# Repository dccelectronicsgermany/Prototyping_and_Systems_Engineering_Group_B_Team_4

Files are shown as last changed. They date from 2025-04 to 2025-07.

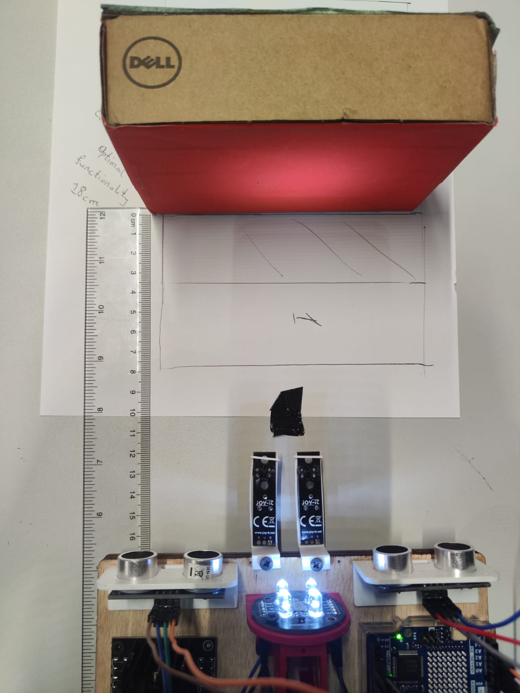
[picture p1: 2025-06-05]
Testing/ColorSensor_Testing/Calibration_of_ColorSensor_ 2025-06-05.jpeg

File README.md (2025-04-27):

## Autonomous Lane-Following and Obstacle-Avoiding Vehicle

 # Project Overview
This project involves the design and implementation of an autonomous vehicle capable of:
- Following a lane based on a color using infrared sensors.
- Detecting obstacles on its path using ultrasonic sensors.
- Changing its route dynamically to avoid obstacles while following the lane.
(without human intervention)

The vehicle uses an Arduino Uno microcontroller and standard robotic hardware components.
 #  Hardware Components
- Chassis (Robot car frame)
- 2 Motor controllers (for driving the wheels)
- 2 Tires
- Breadboard (for circuit prototyping)
- Arduino Uno (central control unit)
- 2 Ultrasonic sensors (for obstacle detection)
- 2 Infrared sensors (for lane detection based on color contrast)
- LiPo Battery (for powering the system)
- ON/OFF Switch (for power management)
 # Functionality Description
- Lane Following:
The vehicle uses two infrared sensors placed underneath to detect lane markings. It adjusts the motor speed and direction to stay within the lane based on color contrast (typically dark lines on a lighter surface).

- Obstacle Detection and Avoidance:
Two ultrasonic sensors monitor the surroundings. When an obstacle is detected within a predefined distance:
The vehicle slows down.
Makes a directional decision (left or right) based on available space.
Reorients itself and continues following the lane.

- Power Management:
The vehicle is powered by a rechargeable LiPo battery, and the system can be turned ON or OFF using a physical switch.

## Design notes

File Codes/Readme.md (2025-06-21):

# Arduino UNO R4 WiFI Modular Robot System

This project is a modular, extensible robot control system based on:

- Line following (PID)
- Obstacle avoidance (Ultrasonic + Color)
- Modular C++ architecture (IR, Motors, PID, Movement...)

## Structure
- `Motor.h/.cpp`: Motor abstraction
- `IRSensor`, `UltrasonicSensor`, `ColorSensor`: Sensor modules
- `MovementController`: Handles motion logic
- `ObstacleHandler`: Obstacle evasion behavior
- `ObstacleChecker`: Central sensor processor
- `PIDController`: For smooth line following

## Board
- Arduino Nano R4 WiFi

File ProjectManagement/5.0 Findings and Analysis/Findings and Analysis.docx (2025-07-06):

Findings and Analysis:

The following section presents the key findings obtained during the project, along with a detailed analysis. These results are based on the data collected, observations made, and methods applied throughout the project.

Sensor Behavior and Accuracy

- Ultrasonic Sensors: Successfully detected obstacles within a range of 18cm with an average error margin of ±1cm.
- Infrared Sensors: Accurately detected line paths, but performance was affected by lighting and surface texture.
- Colour Sensor: Could reliably distinguish between Red and Green surfaces under good lighting conditions.

PID Controller Tuning

- Initial PID values: Kp = 100, Ki = 100, Kd = 100
- Observed that:
  - High Kp caused the robot to oscillate.
  - Ki helped reduce long term drift but too much made it unstable.
  - Kd improved sharp turns and reduced overshoot.
- Final tuned values: Kp = 10, Ki = 5, Kd = 10 – provided smooth line following with minimal overshooting.

State Machine Performance

- The state transitions worked correctly between:
  - Line following
  - Obstacle avoidance
  - Turning logic
- Edge cases (e.g., obstacles, tight corners) were handled with a delay of 200ms on average.

System Limitations

- Sensor noise occasionally caused false obstacle detection.
- Bright ambient light interfered with IR accuracy.
- Tuning PID required trial and error and was environment dependent.

Performance Metrics

- Average lap time on test track: 29 seconds
- Success rate for completing track without collision: 90%

A pre-requisite report for completion of Prototyping and Systems Engineering Course: To: Professor Stephen Henkler By Group B 4 students : Chimezie, Daniel Chidi [ Mat.Nr. 1230515 ] daniel-chidi.chimezie@stud.hshl.de Cho Bertrand Mungu [ Mat.Nr. 2220052 ] bertrand-mungu.cho@stud.hshl.de Ghimire, R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

2 SYSTEMS ENGINEERING AND PROTOTYPING COURSE Prototyping Technical Report: The Design and Construction of Autonomous Vehicle

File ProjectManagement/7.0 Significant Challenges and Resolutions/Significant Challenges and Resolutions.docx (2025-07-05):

Significant Challenges and Resolutions:

Throughout the development and testing of the autonomous vehicle, several technical and practical challenges were encountered. These challenges provided valuable learning opportunities and required iterative problem-solving, adjustments to the hardware and software, and fine-tuning of system performance. Below is a summary of the key challenges faced during the project and the solutions implemented to overcome them.

Sensor Inaccuracy and Interference

- Challenge: The IR and ultrasonic sensors sometimes gave inconsistent or false readings, especially in bright lighting or when objects were at awkward angles.
- Resolution: Implemented multiple readings and averaging (for color sensor), timing intervals for ultrasonic checks and added logic to ignore clearly invalid values.

Obstacle Avoidance Complexity

- Challenge: Designing an effective obstacle avoidance routine that didn’t cause the robot to get lost or stuck after detouring.
- Resolution: Created a step-by-step avoidance sequence including reverse, pivot, bypass, and line recovery with fail-safe search patterns -ensured the robot could return to the line reliably.

Line Loss and Path Recovery

- Challenge: When both IR sensors lost the line (e.g., at junctions or sharp curves), the robot didn’t always know which way to turn.
- Resolution: Tracked the last seen position of the line using lastSeenLine logic and implemented directional searches (pivot left/right) to regain the path.

Color Detection Reliability

- Challenge: Colours were sometimes misclassified due to ambient lighting or variations in surface tone.
- Resolution: Collected calibrated colour ratios (RG and RB) and added a differential comparison strategy instead of relying on raw RGB values - improved classification accuracy between Colour A and B.

Tuning PID Controller

- Challenge: The robot either over-corrected or didn't respond well to line deviations during movement.
- Resolution: Tuned the PID constants (Kp, Ki, Kd) through trial and error to achieve smoother turns and better line-following stability.

Code Integration and Timing Conflicts

- Challenge: Running multiple sensor routines (IR, ultrasonic, colour) caused timing conflicts and delayed responses.
- Resolution: Used timing intervals (millis) instead of delay() for obstacle checks and optimized sensor polling frequency to balance responsiveness and stability.

A pre-requisite report for completion of Prototyping and Systems Engineering Course: To: Professor Stephen Henkler By Group B 4 students : Chimezie, Daniel Chidi [ Mat.Nr. 1230515 ] daniel-chidi.chimezie@stud.hshl.de Cho Bertrand Mungu [ Mat.Nr. 2220052 ] bertrand-mungu.cho@stud.hshl.de Ghimire, R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

2 SYSTEMS ENGINEERING AND PROTOTYPING COURSE Prototyping Technical Report: The Design and Construction of Autonomous Vehicle

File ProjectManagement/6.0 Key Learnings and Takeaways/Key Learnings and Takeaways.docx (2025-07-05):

Key Learnings and Takeaways:

Working on the autonomous vehicle gave us valuable insight into how complex it can be to design a functional system in real life. Some of the major takeaways we had include;

Understanding Autonomous Systems

- Gained practical insight into how autonomous vehicles perceive their environment using sensors like ultrasonic, Infrared and color sensors.
- Learned how decision making is handled through state machines and sensor inputs.

Sensor Integration Challenges

- Realized that real world sensor data is noisy and can be affected by environmental conditions (e.g., lighting, surface reflectivity).

PID Control in Real Life

- Learned how a PID controller is used to achieve smooth line following.
- Understood the role of tuning kp, ki and kd for optimal movement balancing responsiveness and stability.

System Thinking

- Understood the importance of combining hardware, software and control logic into a cohesive system.
- Experienced how small issues in one component (e.g., a sensor) can impact overall system behavior.

Programming and Logic Development

- Improved skills in C/C++ programming using Arduino IDE.
- Learned to design modular code with functions, state machines and helper routines.
- Developed debugging skills by using serial output for troubleshooting sensor behavior.

Project Planning and Iteration

- Learned the value of testing in stages – first the motors, then sensors and then integration.
- Iteratively refined the system through testing, debugging and improvements.

A pre-requisite report for completion of Prototyping and Systems Engineering Course: To: Professor Stephen Henkler By Group B 4 students : Chimezie, Daniel Chidi [ Mat.Nr. 1230515 ] daniel-chidi.chimezie@stud.hshl.de Cho Bertrand Mungu [ Mat.Nr. 2220052 ] bertrand-mungu.cho@stud.hshl.de Ghimire, R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

2 SYSTEMS ENGINEERING AND PROTOTYPING COURSE Prototyping Technical Report: The Design and Construction of Autonomous Vehicle

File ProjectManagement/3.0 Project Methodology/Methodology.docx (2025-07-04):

3. Project Methodology:

. Methodology

The development of the autonomous robotic vehicle was carried out in structured phases, covering mechanical design, sensor calibration, embedded software development, and iterative testing.

Hardware Design

A two-wheeled differential drive robotic chassis was constructed, integrating essential components for autonomous navigation and decision-making. The key hardware includes:

- Arduino Uno R4 microcontroller – acts as the central control unit for all peripherals.
- IR lane-following sensors – detect the contrast between the lane and the background.
- Ultrasonic sensors (HC-SR04) – provide obstacle distance measurements for real-time avoidance.
- TCS3200 color sensor – a color-to-frequency converter used to detect the color of objects based on RGB reflectance.
- SBC Motor Driver 2 – controls the motors with suitable current and voltage for bidirectional motion.
- 12V LiPo battery with switch – powers the entire system, providing consistent voltage and current for reliable operation.

The mechanical frame, including chassis structure, sensor holders, and battery mounts, was designed using SolidWorks. This CAD-based approach ensured accurate placement, structural integrity, and modular design for component accessibility and replacement.

Sensor Calibration and Integration

All sensors were calibrated and tested before integration to ensure accurate data acquisition and system stability:

- IR Sensors: Tuned to detect lane boundaries using reflectance-based thresholding, optimized for the test surface.
- Ultrasonic Sensors: Configured with distance thresholds to trigger avoidance behavior when obstacles are within proximity.
- TCS3200 Color Sensor: Calibrated using reference color samples. The sensor uses photodiodes with RGB filters and outputs a frequency proportional to the intensity of each component. Color classification was achieved by comparing frequency ratios of red, green, and blue channels.

Software Development

Firmware was written using the Arduino IDE in C++, with a modular structure for sensor reading, motor control, and decision logic:

- Lane Following: Implemented with basic PID logic to maintain position within the lane using IR sensor input.
- Obstacle Avoidance: Ultrasonic data triggered directional changes when obstacles were detected within a predefined range.
- Color-Based Behavior: TCS3200 output was analyzed to determine object color and adjust behavior accordingly—e.g., stopping or rerouting.

Testing and Iteration

The system was tested under different physical and environmental conditions to ensure functionality and robustness:

- Sensor Accuracy: Each sensor’s performance was verified under varying lighting and surface reflectivity conditions.
- Navigation Robustness: Evaluated system behavior during lane exits, sharp turns, and reentry, ensuring consistent responsiveness.
- Environmental Adaptability: Testing included both indoor and semi-outdoor environments to assess sensor stability and overall system reliability.

Each iteration guided hardware and software refinements, with component placements and mountings reworked in SolidWorks for better alignment and stability, resulting in a reliable and efficient robotic system.

A pre-requisite report for completion of Prototyping and Systems Engineering Course: To: Professor Stephen Henkler By Group B 4 students : Chimezie, Daniel Chidi [ Mat.Nr. 1230515 ] daniel-chidi.chimezie@stud.hshl.de Cho Bertrand Mungu [ Mat.Nr. 2220052 ] bertrand-mungu.cho@stud.hshl.de Ghimire, R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

4 SYSTEMS ENGINEERING AND PROTOTYPING COURSE Prototyping Technical Report: The Design and Construction of Autonomous Vehicle

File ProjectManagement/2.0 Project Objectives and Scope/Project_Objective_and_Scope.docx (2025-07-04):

2. Project Objectives and Scope:

The primary objective of this project is to design and

develop an autonomous robotic vehicle capable of navigating

dynamic environments using a sensor-driven control system.

The following key goals guide the design and implementation

phases:

• Autonomous Lane Following: Develop a reliable lane-

following mechanism using Infrared (IR) sensors. The

system should be capable of detecting and tracking pre-

defined lanes with precision, including handling curves

and intersections effectively.

• Obstacle Detection and Avoidance: Integrate ultrasonic

sensors to facilitate real-time obstacle detection. The

robotic vehicle should be able to measure distance to

nearby objects and initiate avoidance maneuvers au-

tonomously to prevent collisions.

• Color-Based Decision Making: Implement a color

recognition system to classify and respond to different

types of obstacles. For example, red objects may signal a

full stop, while green may indicate a clear path or require

an alternate route. This enables dynamic and context-

aware navigation.

• Modular and Power-Efficient Design: Design the hard-

ware to be modular, allowing easy replacement and

testing of individual components. Power efficiency will

be emphasized to prolong operational time, utilizing op-

timized power management strategies across all modules.

Scope of the Project

This project encompasses both hardware and embedded

software development, with a strong emphasis on reliability,

sensor fusion, and system integration. Key aspects of the scope

include:

• Hardware Integration and Mechanical Design: Selec-

tion, configuration, and interfacing of sensors (IR and

ultrasonic), motor drivers, microcontrollers, and power

supply units. Custom mechanical components—such

as sensor holders, battery enclosures, and structural

frames—were designed using SolidWorks. This CAD-

based approach allowed for accurate measurements, mod-

ularity, and efficient assembly of all physical parts.

• Software Development: Development of embedded

firmware to process sensor data, control actuators, and

execute decision-making algorithms. Emphasis will be

placed on efficient code structure, interrupt-driven design,

and real-time responsiveness.

• System Testing and Validation: Rigorous testing will

be conducted to evaluate the system’s performance under

different environmental conditions. This includes assess-

ing the accuracy of lane-following, obstacle detection

range, decision logic correctness, and overall system

robustness.

• Scalability and Extensibility: While the initial prototype

will demonstrate core functionalities, the system will be

designed with future enhancements in mind, including

potential wireless communication, machine learning in-

tegration, or advanced navigation algorithms.

In summary, this project aims to deliver a functional,

intelligent robotic vehicle by effectively integrating sensing,

decision-making, mechanical design, and control into a uni-

fied, modular, and energy-efficient system.

A pre-requisite report for completion of Prototyping and Systems Engineering Course: To: Professor Stephen Henkler By Group B 4 students : Chimezie, Daniel Chidi [ Mat.Nr. 1230515 ] daniel-chidi.chimezie@stud.hshl.de Cho Bertrand Mungu [ Mat.Nr. 2220052 ] bertrand-mungu.cho@stud.hshl.de Ghimire, R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

5 SYSTEMS ENGINEERING AND PROTOTYPING COURSE Prototyping Technical Report: The Design and Construction of Autonomous Vehicle

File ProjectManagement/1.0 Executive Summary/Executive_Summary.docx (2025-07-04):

1. Executive Summary:

The rapid advancement of automation and embedded systems has paved the way for intelligent robotic platforms that can perform tasks with minimal human intervention. This project focuses on designing and implementing an autonomous robotic vehicle that can follow a defined path and avoid obstacles using a combination of infrared (IR), ultrasonic, and color sensors. The goal is to develop a functional prototype that simulates intelligent pathfinding and decision-making mechanisms suitable for real-world environments such as automated delivery systems or industrial navigation.

The robotic system is equipped with IR sensors to detect black lines on a contrasting surface, enabling it to follow a designated route. Ultrasonic sensors serve as proximity detectors, allowing the robot to recognize and react to obstacles within its path. A color sensor is also integrated to enhance decision-making by identifying the color characteristics of encountered objects. Based on predefined color criteria, the robot can classify objects such as `Color A` and `Color B`, influencing its navigation behavior accordingly.

A key highlight of the system is its modularity and low cost. The robot is built on a simple two-wheel chassis and powered by an Arduino Uno R4 microcontroller. Peripheral components, including an L298N motor driver, a 7.4V LiPo battery, and a power switch, provide essential control and energy management. This architecture supports expandability and makes the robot suitable for educational and research-oriented applications.

The software architecture is implemented using the Arduino IDE in embedded C++, with a focus on real-time performance. The line-following algorithm relies on digital feedback from the IR sensors, while obstacle avoidance is triggered by distance thresholds defined for the ultrasonic sensor. When an obstacle is detected, the robot either pauses or takes a detour, depending on the color of the object. For example, if the color sensor identifies a specific hue within a known RGB ratio range (Color A or B), the robot modifies its path accordingly—either rerouting, stopping, or re-centering on the line after bypassing the obstacle.

The development process was iterative, involving extensive hardware calibration and software testing under different lighting and surface conditions. The IR sensors were tuned for high contrast detection, and ultrasonic sensor readings were smoothed to minimize false positives. Color detection was verified using known samples to ensure consistent classification accuracy.

As of this report, the robot reliably demonstrates autonomous line-following behavior, detects and avoids obstacles within a 25 cm range, and reacts differently based on object color. This project serves as a practical proof-of-concept for sensor integration and autonomous decision-making in embedded systems, laying the foundation for more advanced robotics projects in the future.

A pre-requisite report for completion of Prototyping and Systems Engineering Course: To: Professor Stephen Henkler By Group B 4 students : Chimezie, Daniel Chidi [ Mat.Nr. 1230515 ] daniel-chidi.chimezie@stud.hshl.de Cho Bertrand Mungu [ Mat.Nr. 2220052 ] bertrand-mungu.cho@stud.hshl.de Ghimire, R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

2 SYSTEMS ENGINEERING AND PROTOTYPING COURSE Prototyping Technical Report: The Design and Construction of Autonomous Vehicle

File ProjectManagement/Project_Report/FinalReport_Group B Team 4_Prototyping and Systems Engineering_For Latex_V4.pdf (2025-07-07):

## UNIVERSITY OF APPLIED SCIENCES, HAMM-LIPPSTADT, GERMANY

### SYSTEMS ENGINEERING AND PROTOTYPING

### DESIGN AND IMPLEMENTATION OF A LINE FOLLOWING AND OBSTACLE AVOIDANCE ROBOT

### A COURSE WORK PROJECT FOR SUMMER SEMESTER 2025:

### A PREREQUISITE FOR COMPLETION OF PROTOTYPING AND SYSTEMS ENGINEERING COURSE AT THE UNIVERSITY OF APPLIED SCIENCES, HAMM-LIPPSTADT

## PRESENTED TO:

## PROFESSOR STEFAN HENKLER DR. FAEZEH PASANDIDEH MR. GIDO WAHRMANN

BY:

## GROUP B TEAM 4

## CHIMEZIE, DANIEL CHIDI / MAT.NR. 1230515 / DANIEL-CHIDI.CHIMEZIE@STUD.HSHL.DE

## CHO, BERTRAND MUNGU / MAT.NR. 2220052 / BERTRAND-MUNGU.CHO@STUD.HSHL.DE

## GHIMIRE, RIWAJ / MAT.NR. 1232171 / RIWAJ.GHIMIRE@STUD.HSHL.DE

## JULY 8, 2025

2 | P a g e

## 1.0 EXECUTIVE SUMMARY

The rapid advancement of automation and embedded systems have paved the way for the development of intelligent robotic systems that can perform tasks with minimal human intervention. This project focuses on designing and implementing an autonomous robotic vehicle that can follow a defined path and avoid obstacles using a combination of infrared (IR), ultrasonic and color sensors. The goal is to develop a functional prototype that simulates intelligent pathfinding and decision-making mechanisms suitable for real-world environments such as automated delivery systems or industrial navigation.

The robotic system is equipped with IR sensors to detect black lines on a contrasting surface, enabling it to follow a designated route. Ultrasonic sensors serve as proximity detectors, allowing the robot to recognize and react to obstacles within its path. A color sensor is also integrated to enhance decision-making by identifying the color characteristics of encountered objects. Based on predefined color criteria, the robot can classify objects such as `Color A` and `Color B`, influencing its navigation behavior accordingly [2].

A key highlight of the system is its modularity and low cost. The robot is built on a simple three-wheel chassis and powered by an Arduino Uno R4 Wi-Fi microcontroller. Peripheral components, including an L298N motor driver, a 12 V LiPo battery, and a power switch, provide essential control and energy management. This architecture supports expandability and makes the robot suitable for educational and research-oriented applications[4].

The software architecture is implemented using the Arduino IDE [1] in embedded C++, with a focus on real-time performance. The line-following algorithm relies on digital feedback from the IR sensors, while obstacle avoidance is triggered by distance thresholds defined for the ultrasonic sensor [2]. When an obstacle is detected, the robot either pauses or takes a detour, depending on the color of the object. For example, if the color sensor identifies a specific hue within a known RGB ratio range (Color A or B), the robot modifies its path accordingly, by either rerouting, stopping or re-centering on the line after bypassing the obstacle.

The development process was iterative, involving extensive hardware calibration and software testing under different lighting and surface conditions. The IR sensors were tuned for high contrast detection, and ultrasonic sensor readings were smoothed to minimize false positives. Color detection was verified using known samples to ensure consistent classification accuracy [2].

The robot we developed reliably demonstrates autonomous line-following behavior, detects and avoids obstacles within a 25 cm range, and reacts differently based on object color. This project serves as a practical proof-of-concept for sensor integration and autonomous decision-making in embedded systems, laying the foundation for more advanced robotics projects in the future.

3 | P a g e

## 2.0 PROJECT OBJECTIVES AND SCOPE

### 2.1 Objective:

The primary objective of this project is to design and develop an autonomous robotic vehicle capable of navigating dynamic environments using a sensor driven control system.

The following key goals guide the design and implementation phases:

a) Autonomous Lane Following: Develop a reliable lane-following mechanism using Infrared (IR) sensors. The system should be capable of detecting and tracking pre-defined lanes with precision, including handling curves and intersections effectively.
b) Obstacle Detection and Avoidance: Integrate ultrasonic sensors to facilitate real-time obstacle detection. The robotic vehicle should be able to measure distance to
nearby objects and initiate avoidance manoeuvres autonomously to prevent collisions[2].
c) Colour-Based Decision Making: Implement a colour recognition system to classify and respond to different types of obstacles. For example, red objects may signal a full stop, while green may indicate a clear path or require an alternate route. This enables dynamic and context-aware navigation.
d) Modular and Power-Efficient Design: Design the hardware to be modular, allowing easy replacement and testing of individual components. Power efficiency will be emphasized to prolong operational time, utilizing optimized power management strategies across all modules.

### 2.2 Project scope:

This project encompasses both hardware and embedded software development, with a strong emphasis on reliability, sensor fusion, and system integration. Key aspects of the scope include:

a) Hardware Integration and Mechanical Design: Selection, configuration and interfacing of sensors (IR, Colour and ultrasonic), motor drivers, microcontrollers, and power supply units. Custom mechanical components such as sensor holders, battery enclosures, and structural frames were designed using SolidWorks. This CAD-based approach allowed for accurate measurements, modularity, and efficient assembly of all physical parts[4].
b) Software Development: Development of embedded firmware to process sensor data, control actuators, and execute decision-making algorithms. Emphasis will be placed on efficient code structure, interrupt-driven design and real-time responsiveness.
c) System Testing and Validation: Rigorous testing will be conducted to evaluate the system’s performance under different environmental conditions. This includes assessing the accuracy of lane-following, obstacle detection range, decision logic correctness, and overall system robustness.
d) Scalability and Extensibility: While the initial prototype will demonstrate core functionalities, the system will be designed with future enhancements in mind, including potential wireless communication, machine learning integration, or advanced navigation algorithms.
In summary, this project aims to deliver a functional, intelligent robotic vehicle by effectively integrating sensing, decision-making, mechanical design, and control into a unified, modular, and energy-efficient system.

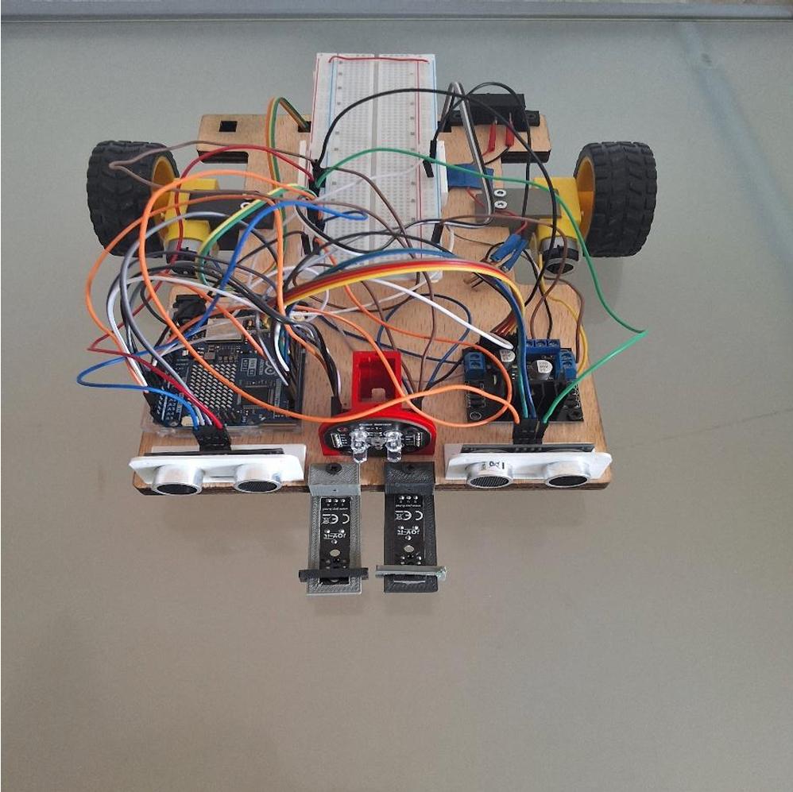
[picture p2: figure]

4 | P a g e

## 3.0 PROJECT METHODOLOGY

The primary objective of this project is to design and develop an autonomous robotic vehicle capable of navigating dynamic environments using a sensor-driven control system.

The following key goals guide the design and implementation phases:

a) Autonomous Lane Following: To develop a reliable lane-following mechanism using Infrared (IR) sensors. The system should be capable of detecting and tracking pre-defined lanes with precision, including handling curves and intersections effectively.
b) Obstacle Detection and Avoidance: To integrate ultrasonic sensors to facilitate real-time obstacle detection. The robotic vehicle should be able to measure distance to nearby objects and initiate avoidance manoeuvres autonomously to prevent collisions [2].
c) Colour-Based Decision Making: To implement a colour recognition system to classify and respond to different types of obstacles. For example, red objects may signal a full stop, while green may indicate a clear path or require an alternate route. This enables dynamic and context-aware navigation.
d) Modular and Power-Efficient Design: Design the hardware to be modular, allowing easy replacement and testing of individual components. Power efficiency will be emphasized to prolong operational time, utilizing optimized power management strategies across all modules.

## 3.1 Mechanical Designs:

## CAD Designs of spare parts using SolidWorks Software

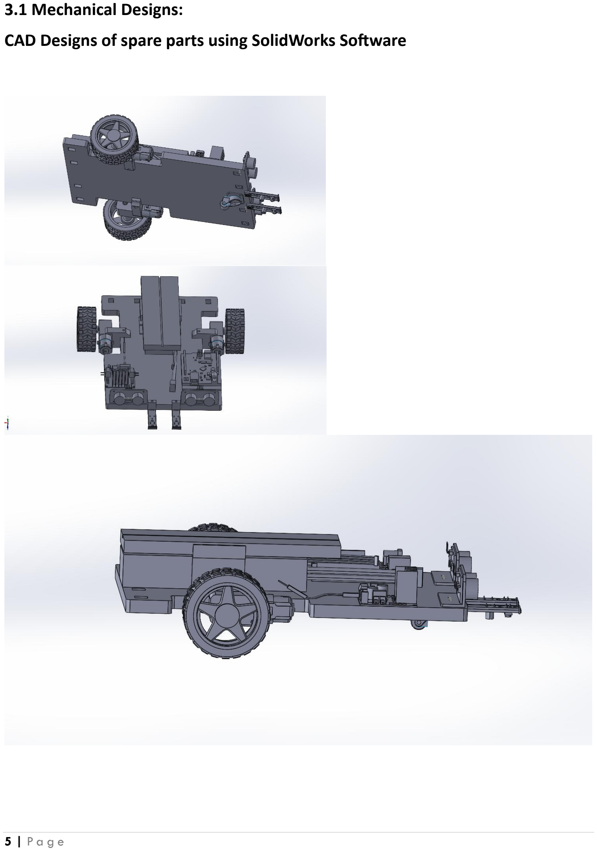
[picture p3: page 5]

5 | P a g e

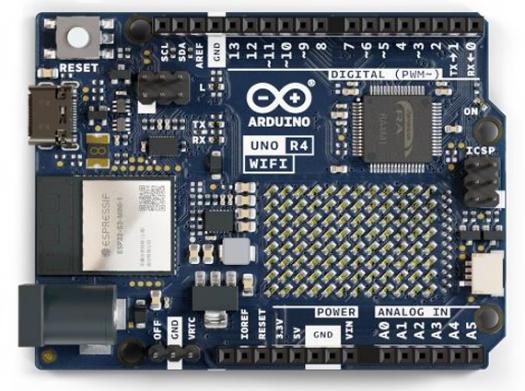
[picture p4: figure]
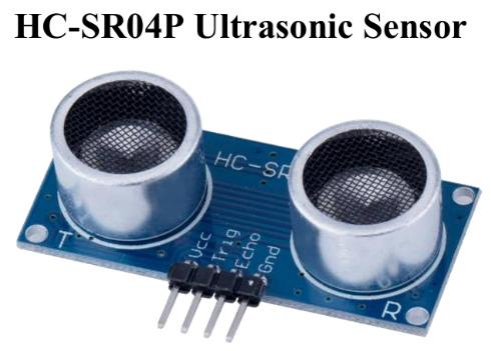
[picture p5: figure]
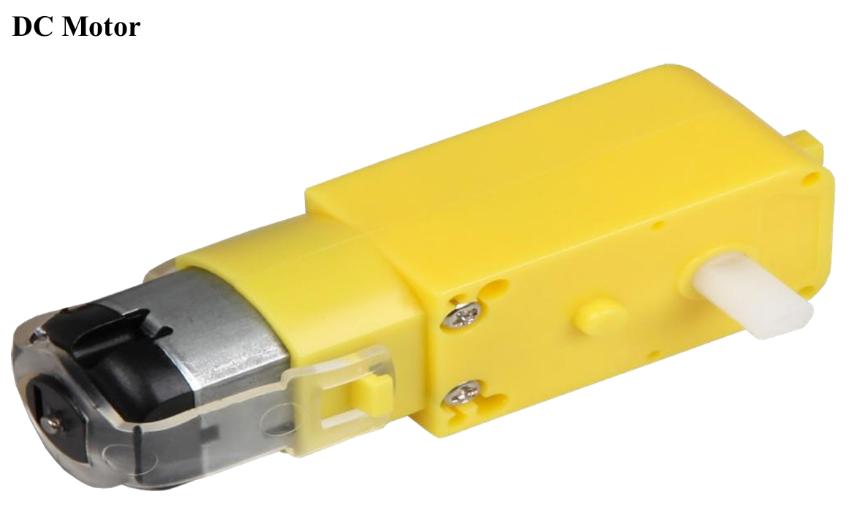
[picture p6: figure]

6 | P a g e

## 3.2 Electrical Components

Arduino Uno R4 WiFi | SBC-Motor Driver 2 | IR Sensor

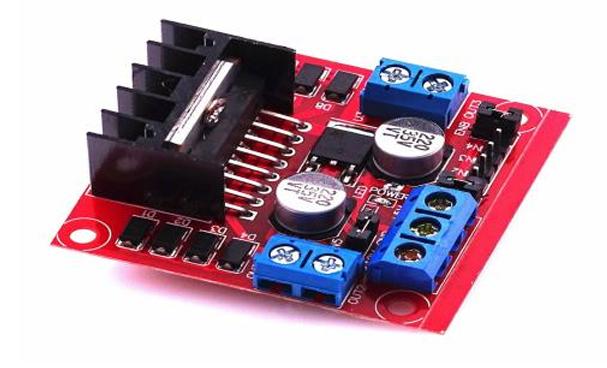
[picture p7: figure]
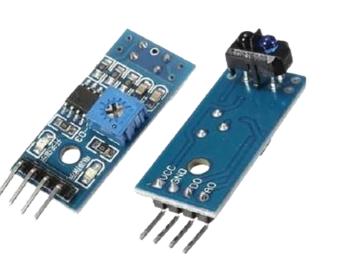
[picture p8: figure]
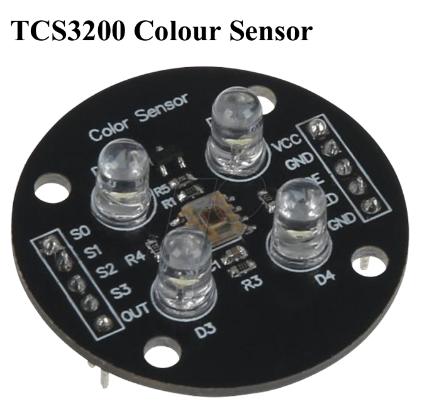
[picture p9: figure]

## 3.2.1 Electrical Schematics and Arrangements:

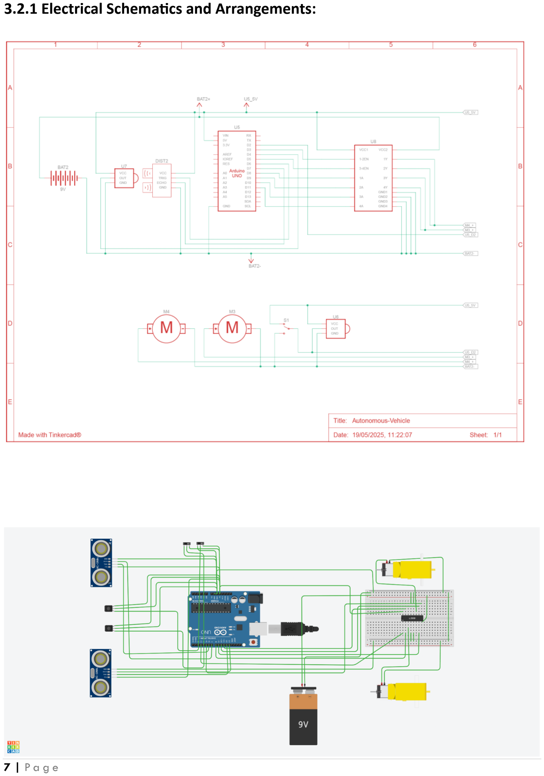
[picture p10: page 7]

7 | P a g e

## 3.3 System Engineering Architecture

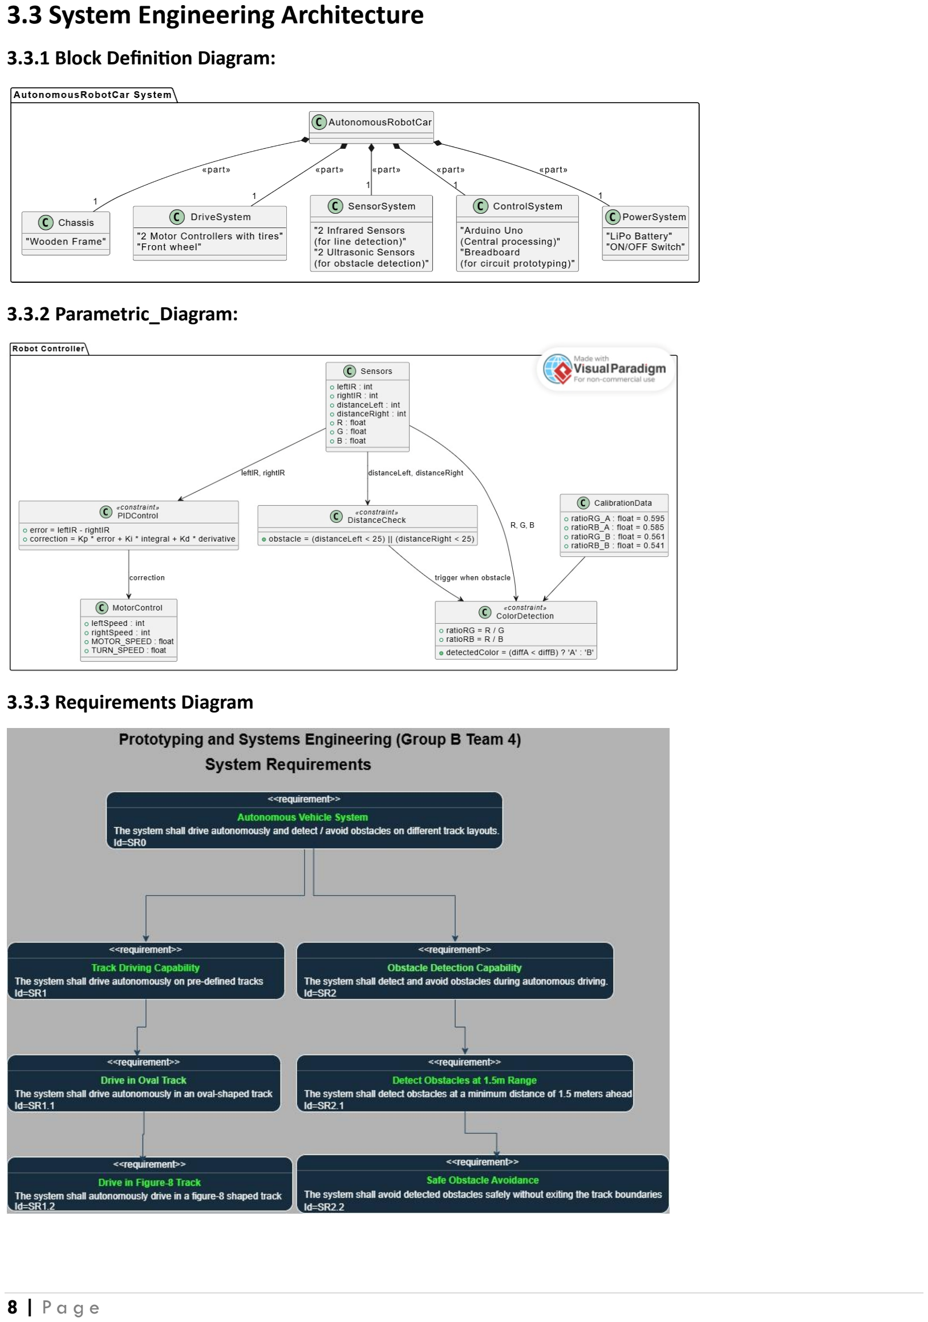
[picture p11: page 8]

8 | P a g e

### 3.3.1 Block Definition Diagram:

### 3.3.2 Parametric_Diagram:

### 3.3.3 Requirements Diagram

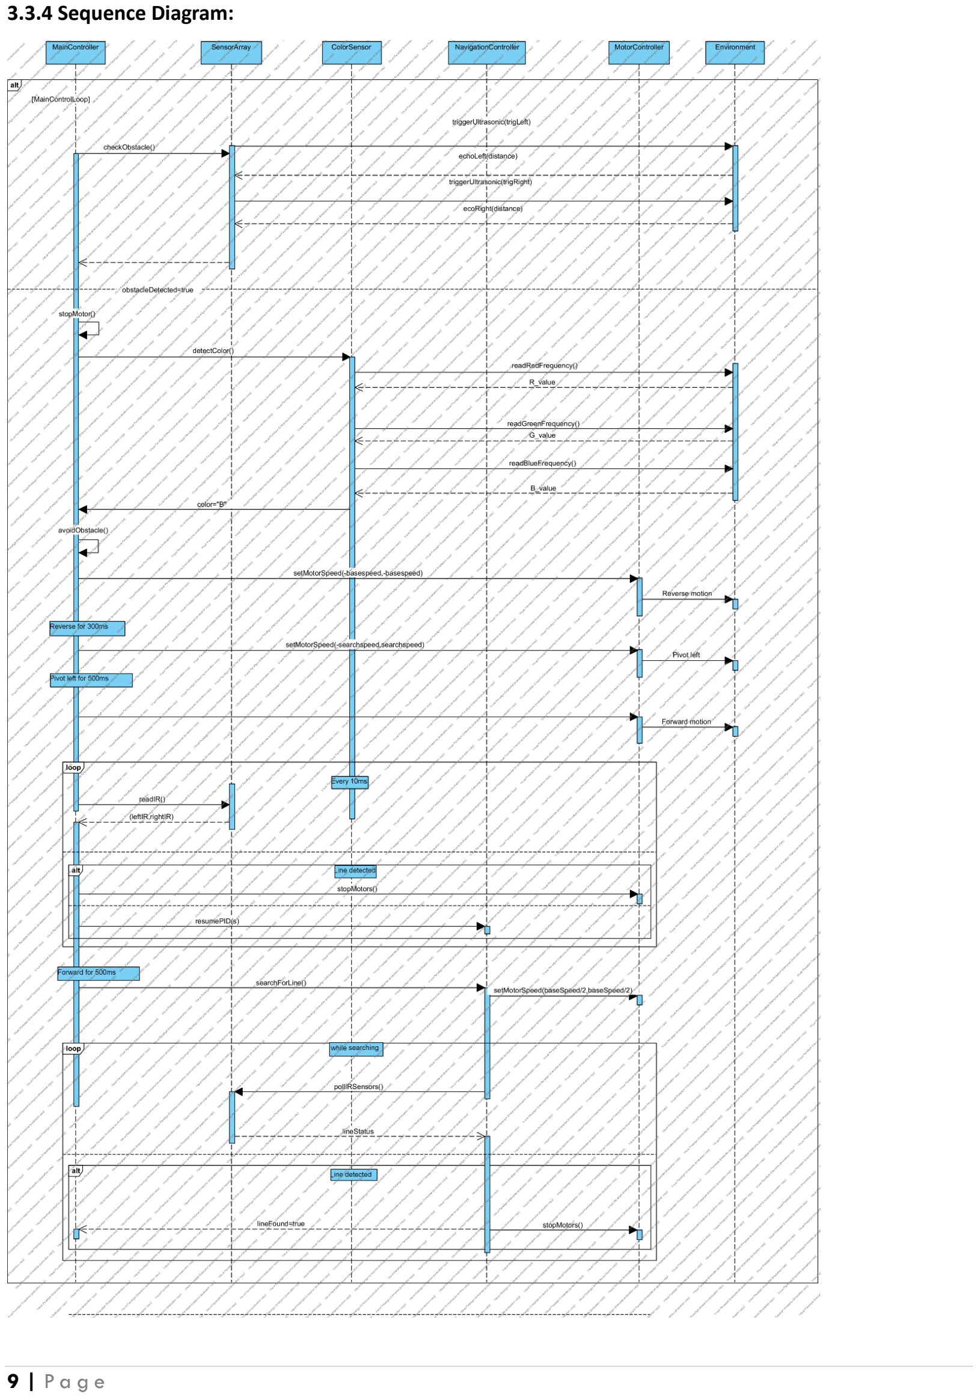
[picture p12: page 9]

9 | P a g e

### 3.3.4 Sequence Diagram:

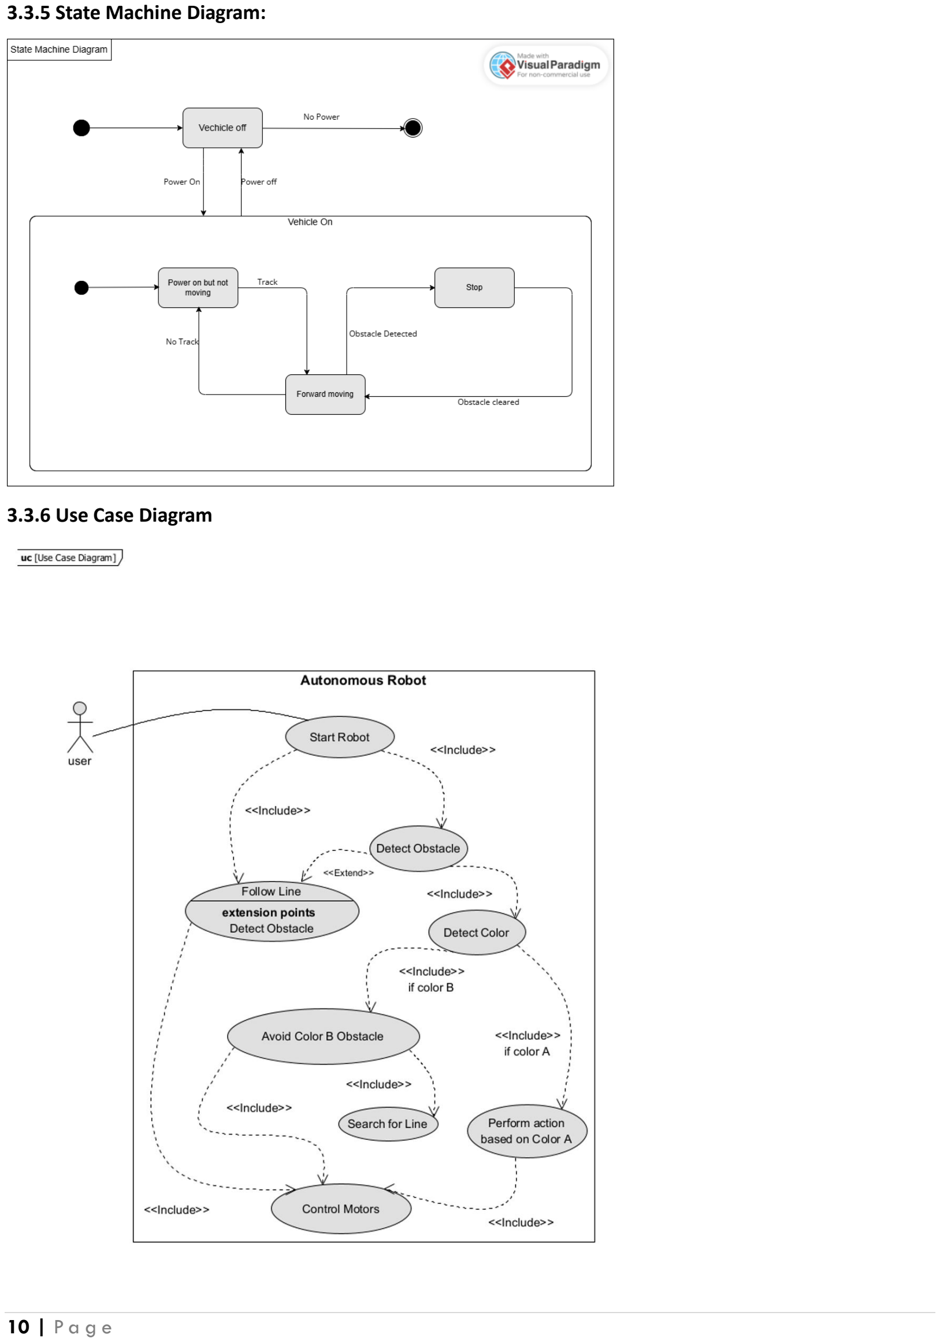
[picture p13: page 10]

10 | P a g e

### 3.3.5 State Machine Diagram:

### 3.3.6 Use Case Diagram

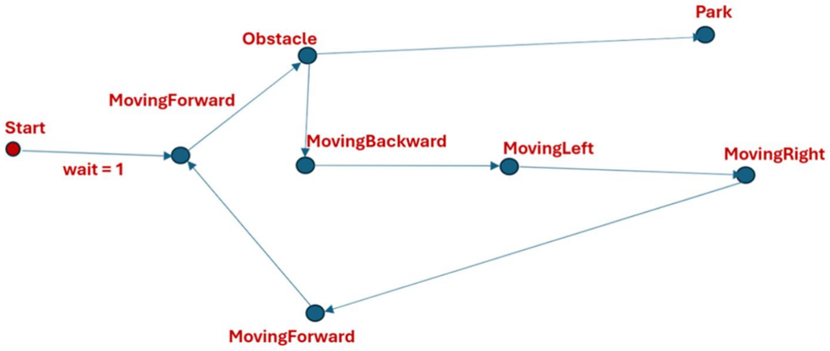
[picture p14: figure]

11 | P a g e

### 3.3.7 UPAAL Model Diagram

12 | P a g e

## 4.0 PROGRESS SUMMARY

The project successfully reached completion after progressing through several structured development stages:

a) Mechanical Design:
The project began with systems engineering training and receipt of the project requirement from the professor. Thereafter, the mechanical parts were received in the lab. Custom holders for sensors and the battery were designed by us using SolidWorks and fabricated using a 3D printer. These additional parts provided a stable and modular foundation for effective assembly and efficient performance of our vehicle [10].
b) Component Integration:
Once the frame and holders were ready, each electronic component was tested individually. The IR sensors, ultrasonic sensors, TCS3200 colour sensor, motor driver (SBC Motor Driver 2), and 12V LiPo battery were all verified for functionality before being integrated into the autonomous vehicle system[2],[4].
c) Core Functionality Development:
With hardware in place, development moved to software. The robot was programmed to follow a predefined lane using IR sensors, followed by ultrasonic-based obstacle detection within a 25 cm range. The TCS3200 colour sensor was calibrated to distinguish between obstacle types (Colour A and Colour B), enabling the robot to take appropriate actions based on object colour [3].
d) Advanced Behaviour Implementation:
The robot was enhanced with advanced obstacle avoidance manoeuvres. It can now bypass obstacles autonomously and return to the original lane without external assistance. PID control logic was used to ensure smooth lane following and stable turning behaviour.
e) Testing, Challenges, and Finalization:
The system was tested extensively under different lighting and surface conditions. The main challenges included colour sensor calibration in varied lighting and PID tuning for smooth motion. These were overcome through iterative testing and adjustments. All planned objectives were achieved [3].
f) Final Status:
The robotic vehicle demonstrates all core capabilities lane following, real-time obstacle avoidance, colour-based decision making, and autonomous path correction. The final system is stable, efficient, and ready for deployment.

13 | P a g e

## 5.0 FINDINGS AND ANALYSIS

Findings and Analysis:

The following section presents the key findings obtained during the project, along with a detailed analysis. These results are based on the data collected, observations made, and methods applied throughout the project.

### 5.1 Sensor Behaviour and Accuracy:

a) Ultrasonic Sensors: Successfully detected obstacles within a range of 18cm with an average error margin of ±1cm[2].
b) Infrared Sensors: Accurately detected line paths, but performance was affected by lighting and surface texture.
c) Colour Sensor: Could reliably distinguish between Red and Green surfaces under good lighting conditions.

### 5.2 PID Controller Tuning:

a) Initial PID values: Kp = 100, Ki = 100, Kd = 100
b) Observed that:
i. High Kp caused the robot to oscillate.
ii. | Ki helped reduce long term drift but too much made it unstable.
iii. | Kd improved sharp turns and reduced overshoot.
c) Final tuned values: Kp = 10, Ki = 0, Kd = 10 provided smooth line following with minimal overshooting [8].

### 5.3 State Machine Performance:

a) The state transitions worked correctly between:
i. Line following
ii. | Obstacle avoidance
iii. | Turning logic
b) Edge cases (obstacles, tight corners) were handled with a delay of 200ms on average.

### 5.4 System Limitations:

a) Sensor noise occasionally caused false obstacle detection.
b) Bright ambient light interfered with IR accuracy.
c) Tuning PID required trial and error and was environment dependent.

### 5.5 Performance Metrics:

a) Average lap time on test track: 29 seconds
b) Success rate for completing track without collision is 90%.

14 | P a g e

## 6.0 KEY LEARNINGS AND TAKEAWAYS

Key Learnings and Takeaways

Working on the autonomous vehicle gave us valuable insight into how complex it can be to design a functional system in real life. Some of the major takeaways we had include;

### 6.1 Understanding Autonomous Systems:

a) Gained practical insight into how autonomous vehicles perceive their environment using sensors like ultrasonic, Infrared and color sensors.
b) Learned how decision making is handled through state machines and sensor inputs.

### 6.2 Sensor Integration Challenges:

a) Realized that real world sensor data is noisy and can be affected by environmental conditions (for example: lighting and surface reflectivity).

### 6.3 PID Control in Real Life:

a) Learned how a PID controller is used to achieve smooth line following.
b) Understood the role of tuning kp, ki and kd for optimal movement balancing responsiveness and stability.

### 6.4 System Thinking:

a) Understood the importance of combining hardware, software and control logic into a cohesive system.
b) Experienced how small issues in one component (a sensor for instance) can impact overall system behavior.

### 6.5 Programming and Logic Development:

a) Improved skills in C/C++ programming using Arduino IDE [1].
b) Learned to design modular code with functions, state machines and helper routines.
c) Developed debugging skills by using serial output for troubleshooting sensor behavior.

### 6.6 Project Planning and Iteration:

a) Learned the value of testing in stages. Firstly, the motors were tested, then sensors and other components before the integration of the system.
b) Iteratively refined the system through testing, debugging and improvements.

15 | P a g e

## 7.0 SIGNIFICANT CHALLENGES AND RESOLUTIONS

Throughout the development and testing of the autonomous vehicle, several technical and practical challenges were encountered. These challenges provided valuable learning opportunities and required iterative problem-solving, adjustments to the hardware and software, and fine-tuning of system performance. Below is a summary of the key challenges faced during the project and the solutions implemented to overcome them.

### 7.1 Sensor Inaccuracy and Interference:

a) Challenge: The IR and ultrasonic sensors sometimes gave inconsistent or false readings, especially in bright lighting or when objects were at awkward angles [2].
b) Resolution: Implemented multiple readings and averaging (for color sensor), timing intervals for ultrasonic checks and added logic to ignore clearly invalid values.

### 7.2 Obstacle Avoidance Complexity:

a) Challenge: Designing an effective obstacle avoidance routine that didn’t cause the robot to get lost or stuck after detouring.
b) Resolution: Created a step-by-step avoidance sequence including reverse, pivot, bypass, and line recovery with fail-safe search patterns -ensured the robot could return to the line reliably.

### 7.3 Line Loss and Path Recovery:

a) Challenge: When both IR sensors lost the line (e.g., at junctions or sharp curves), the robot didn’t always know which way to turn.
b) Resolution: Tracked the last seen position of the line using lastSeenLine logic and implemented directional searches (pivot left/right) to regain the path.

### 7.4 Color Detection Reliability:

a) Challenge: Colours were sometimes misclassified due to ambient lighting or variations in surface tone.
b) Resolution: Collected calibrated colour ratios (RG and RB) and added a differential comparison strategy instead of relying on raw RGB values - improved classification accuracy between Colour A and B.

### 7.5 Tuning PID Controller:

a) Challenge: The robot either over-corrected or didn't respond well to line deviations during movement.
b) Resolution: Tuned the PID constants (Kp, Ki, Kd) through trial and error to achieve smoother turns and better line-following stability.

### 7.6 Code Integration and Timing Conflicts:

a) Challenge: Running multiple sensor routines (IR, ultrasonic, colour) caused timing conflicts and delayed responses.
b) Resolution: Used timing intervals as millis() instead of delay() for obstacle checks and optimized sensor polling frequency to balance responsiveness and stability.

16 | P a g e

## 8.0 BUDGET AND FINANCES

Budget and Finances:

While working on the project, we realized that extensive testing on the autonomous vehicle was necessary to achieve optimal results. To facilitate this, we purchased a few additional items to support our efforts. Below is a list of the items we acquired:

Cardboards and coloured tapes:

Due to limited lab time for testing, we bought cardboards and coloured tapes to create a temporary track at home. This allowed us to conduct more extensive testing of the autonomous vehicle.

9V Battery:

Since students were not allowed to take the 12V LiPo battery home due to the risk of explosion, we purchased a 9V battery to power the autonomous vehicle during home testing.

3*25mm Screws:

The mounts we designed for the DC motors required 3×25mm screws, which were not available in the lab. We therefore bought the screws specifically for this purpose

HSHL Group B Team 4 Expense Report ( For Team Project Only)

General Information

Purpose: To invest more time in practicing at home before final competition

Date | Description | Quantity | Unit Price | Amount | Total
25/05/2025 | 9V Battery | 1 | 3€ | 3€ | 3€
| White Cardboard | 2 | 1€ | 2€ | 2€
| Coloured Tape Pack | 1 | 3,29€ | 3,29€ | 3,29€
| 3*25mm Screw Pack | 1 | 4,59€ | 4,59€ | 4,59€
Total | | | | | 12,88€
| | | | | 12,88€

## 9.0 TIMELINE AND SCHEDULE

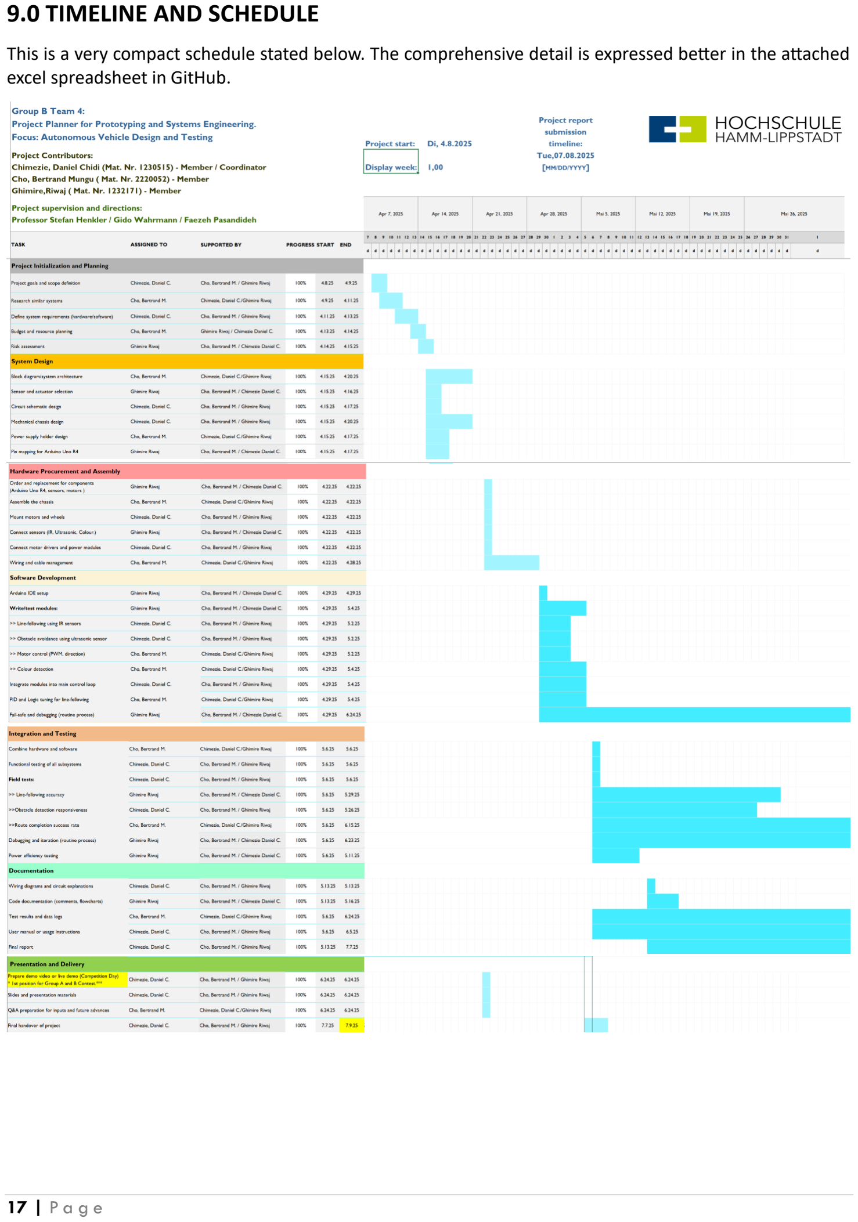
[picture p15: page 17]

17 | P a g e

This is a very compact schedule stated below. The comprehensive detail is expressed better in the attached excel spreadsheet in GitHub.

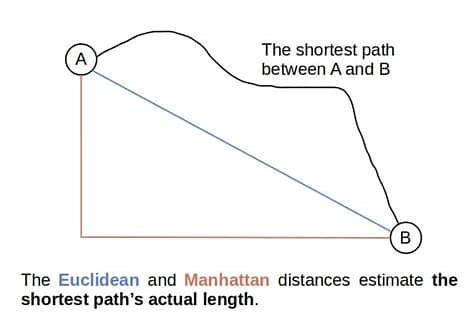
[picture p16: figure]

18 | P a g e

## 10. RECOMMENDATIONS AND NEXT STEPS

The autonomous vehicle project has successfully met its core objectives, including reliable lane following, obstacle avoidance, and colour-based decision making. To further enhance the system’s robustness, scalability, and practical applicability, the following recommendations and next steps are proposed:

a) Improve Sensor Fusion:
Integrate data from multiple sensors (IR, ultrasonic, and camera modules) using sensor fusion techniques to enhance accuracy in complex environments.
b) Add Camera-Based Vision:
Introduce a camera module with basic computer vision algorithms (OpenCV) to recognize traffic signs, lane markings, and dynamic obstacles beyond the capability of IR or colour sensors [9].
c) Enhance Navigation Algorithms:
Implement advanced algorithms such as A* or Dijkstra for path planning, and Kalman Filter for better localization and control under uncertain conditions. [6]
d) Develop a Scalable Software Architecture:
Refactor the current code into modular blocks to support future upgrades, debugging, and potential collaboration with other developers [5], [6], [7].
e) Test in Real-World Scenarios:
Move beyond lab conditions and test the vehicle on larger, more dynamic tracks with real-world variations in lighting, surfaces, and obstacle types. [5], [6], [7].
f) Add Remote Monitoring:
Incorporate wireless communication (e.g., Bluetooth or Wi-Fi) for remote monitoring, telemetry, and control, allowing real-time feedback and data collection during operation.
g) Energy Optimization:
Analyse battery usage and optimize motor control and sensor usage to extend operating time and improve energy efficiency [5], [6], [7].

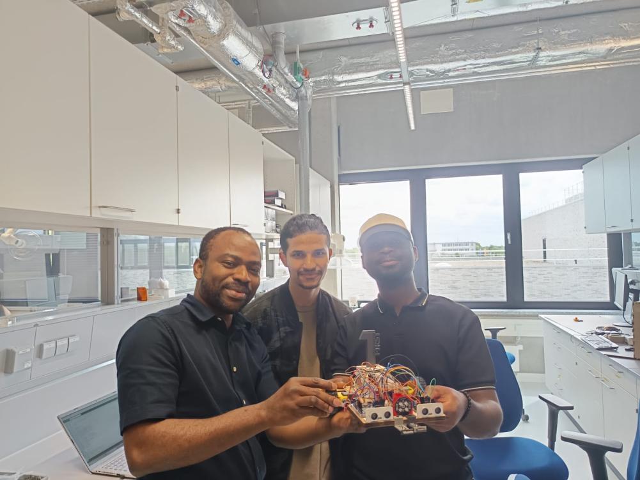
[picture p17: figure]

19 | P a g e

## 11. TEAM PERFORMANCE

We worked extremely very hard and also, invested much time in testing and re-testing to ensure that our modest design meets the core aim of the project which is:

The ability of our designed robot to do the following with success:

a) To follow a dark lane and travel through an oval part.
b) To sense and detect an obstacle and follow our desired instructions in Arduino IDE coding [1].
c) To avoid obstacles it sensed and return back to the lane and continue its travel via the assigned tracks.

For Group A and Group B Teams racing and obstacle avoidance contest, we won the contest with records of less than 29 seconds travel time across the oval.

Future trajectory:

We aim to investigate further into robotics by applying the skills acquired in this course and project in designing a car with similar capabilities which would integrate other capabilities such as artificial intelligence and real life camera sensing devices.

We recommend this course for any Electrical and Electronic Engineering student or any human who is innovative minded. There should be no single limits if we push very hard with unwavering efforts.

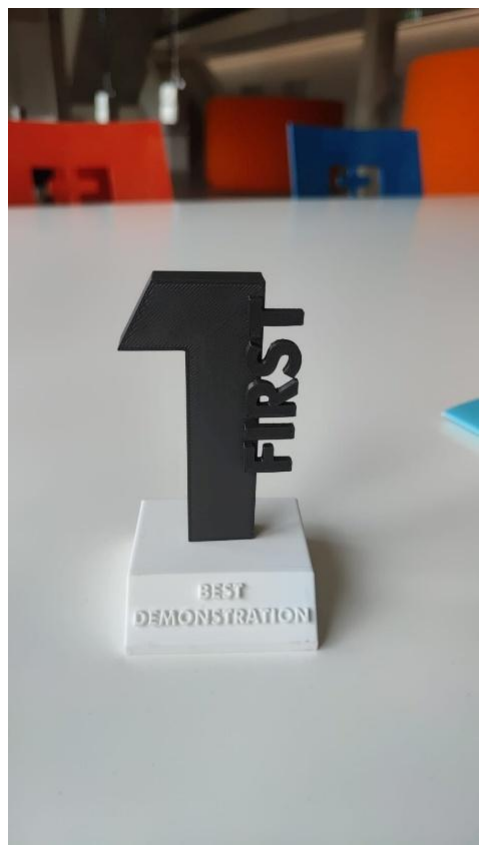
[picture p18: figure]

20 | P a g e

## 12. RISKS AND MITIGATION

Risk | Description | Mitigation Strategy
Sensor Malfunction or Inaccuracy | Inconsistent readings due to lighting, surface reflectivity, or hardware issues | a) Regular calibration under varying conditions. b) Use redundant sensors or sensor fusion. c) Implement error-handling in code.
Power Supply Issues | Battery drain or voltage drops causing system failure | a) Monitor battery voltage in real time. b) Optimize power usage in code -Keep spare batteries on hand.
Software Bugs and Instability | Unexpected behaviour due to bugs or incomplete testing | a) Modular programming with good documentation. b) Conduct unit and integration tests. c) Use version control.
Hardware Damage | Mechanical failure or wear and tear from testing | a) Use durable materials and proper mounting. b) Regular physical inspection. c) Keep spare parts available.
Environmental Variability | Performance drops in outdoor or non-lab settings | a) Test in diverse environments early. b) Use adaptive thresholds and calibration techniques.
Team Coordination and Time Constraints | Delays from poor communication or uneven workload | a) Hold regular team meetings. b) Use project management tools (e.g., Trello, GitHub, MS-PM). c) Allocate buffer time for issues.

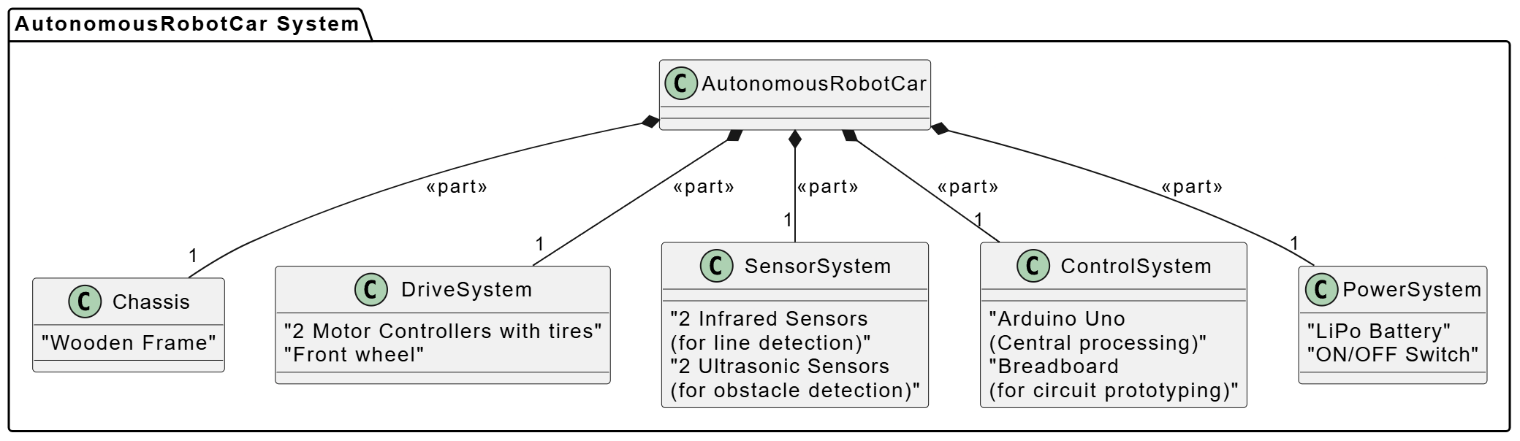
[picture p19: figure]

21 | P a g e

## 13. APPENDICES

All supporting documents including technical specifications, tables, charts, and detailed data

Appendix A: Technical Specifications

Component | Specification
IR Sensors | Digital reflectance sensors, 3–5V, 20–30 cm range
Ultrasonic Sensor | HC-SR04, 2–400 cm range, 5V operating voltage
Color Sensor | TCS3200, RGB color detection, 3–5V input
Motor Driver | SBC Motor Driver 2, dual channel, 5–30V DC
Power Source | 12V LiPo Battery, 2200 mAh
Microcontroller | Arduino Uno R4 WiFI (ATmega328P)
Chassis Material | Acrylic frame with 3D-printed sensor holders
Wheels and Motors | DC geared motors, 100 RPM, plastic wheels

[2], [4].

Appendix B: PID Control Parameters

Parameter Value

P (Proportional) 10

I (Integral) 0

D (Derivative) 10

Appendix C: System Block Diagram

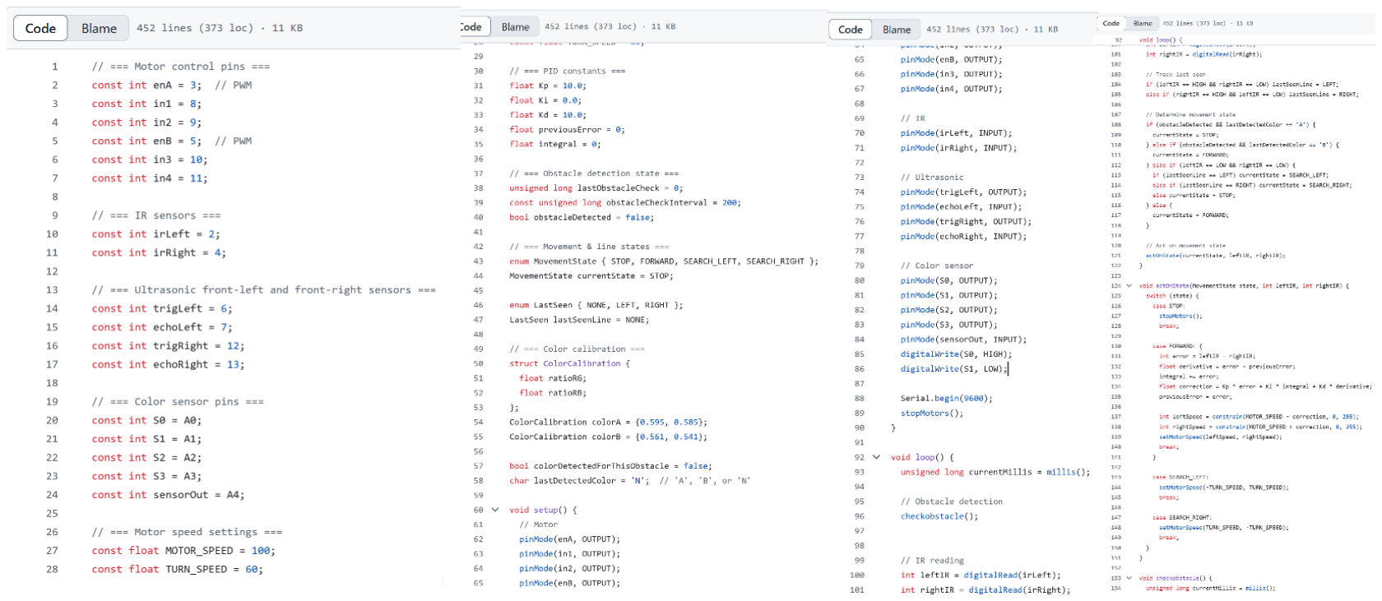
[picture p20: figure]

22 | P a g e

Appendix D: Test Results Summary

Test Scenario | Outcome | Notes
Lane following on white background | Successful | Minor tuning required for sharp turns
Obstacle avoidance at 25 cm | Successful | Smooth detour and return to lane
Colour detection under indoor light | Reliable (Colour A & B detected) | Requires recalibration under sunlight
Battery endurance test | 2.5 hours of operation | Under typical use with full charge

Appendix E: Source Code Snapshots

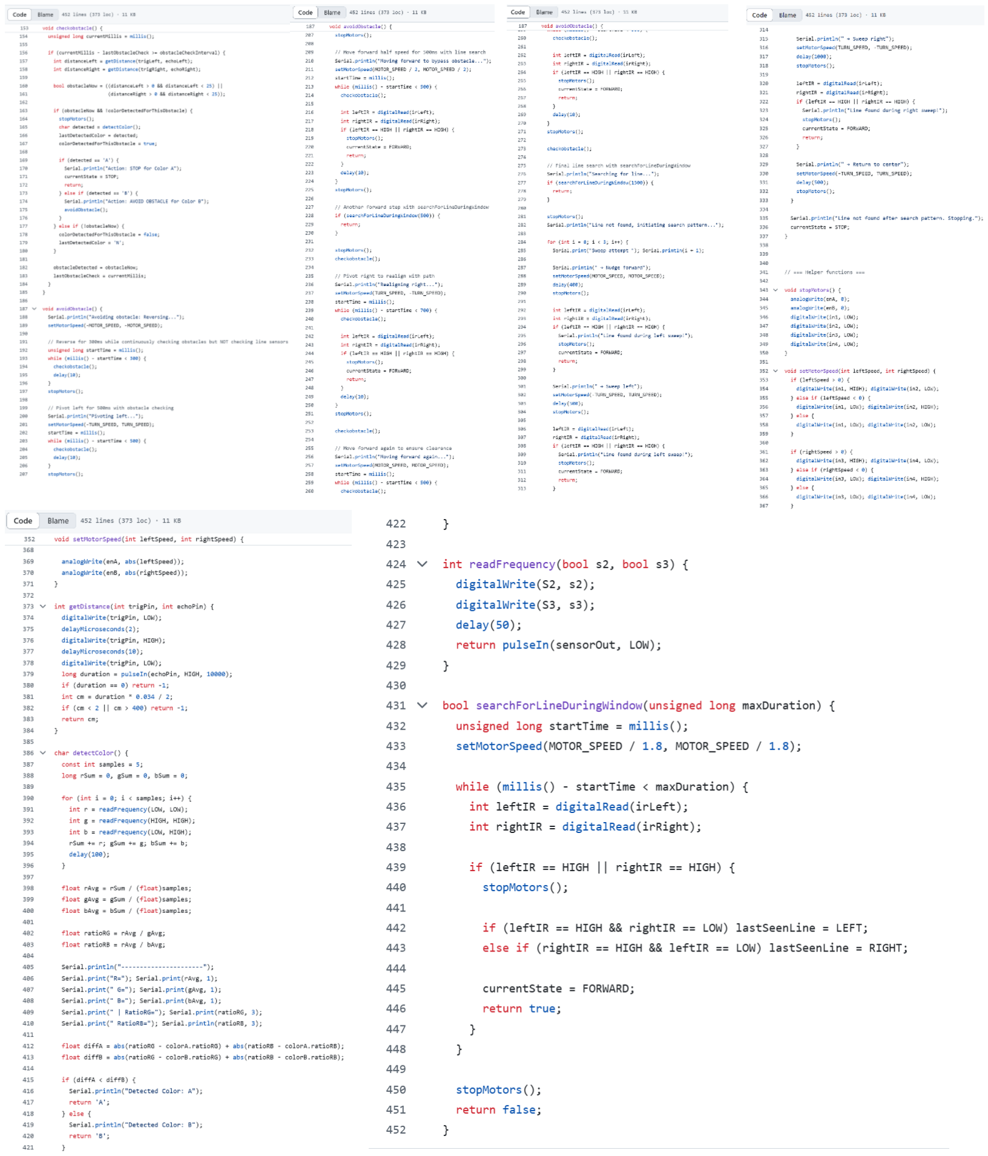
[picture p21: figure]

23 | P a g e

Appendix F: 3D-Printed Part Designs

(a) IR Sensor holder | (b) Motor Holder | (c) Ultrasonic Sensor Holder [2].
(d) IR Sensor Clip | (d) Battery and Breadboard holder

24 | P a g e

## 14.0 REFERENCES (IEEE Standard)

[1] Arduino, “Arduino UNO R4 WiFi,” [Online]. Available: https://www.arduino.cc/reference/en/boards/uno-r4-wifi/. [Accessed: 07-Jul-2025].
[2] HC-SR04 Datasheet, “Ultrasonic Distance Sensor,” [Online]. Available: https://cdn.sparkfun.com/datasheets/Sensors/Proximity/HCSR04.pdf. [Accessed: 07-Jul-2025].
[3] Adafruit, “TCS3200 Colour Sensor,” [Online]. Available: https://learn.adafruit.com/tcs34725-color-sensor. [Accessed: 07-Jul-2025].
[4] Texas Instruments, “L298N Dual H-Bridge Motor Driver Datasheet,” [Online]. Available: https://www.ti.com/lit/ds/symlink/l298.pdf. [Accessed: 07-Jul-2025].
[5] S. Skogestad and I. Postlethwaite, *Multivariable Feedback Control: Analysis and Design*, 2nd ed. Chichester, U.K.: Wiley, 2005.
[6] R. Siegwart, I. R. Nourbakhsh, and D. Scaramuzza, *Introduction to Autonomous Mobile Robots*, 2nd ed. Cambridge, MA: MIT Press, 2011.
[7] D. E. Goldberg, *Genetic Algorithms in Search, Optimization, and Machine Learning*, Reading, MA: Addison-Wesley, 1989.
[8] MathWorks, “PID Controller Tuning,” [Online]. Available: https://www.mathworks.com/help/control/ug/pid-controller.html. [Accessed: 07-Jul-2025].
[9] OpenCV, “Open Source Computer Vision Library,” [Online]. Available: https://opencv.org/. [Accessed: 07-Jul-2025].
[10] SolidWorks, “SOLIDWORKS 3D CAD Software,” Dassault Systèmes, [Online]. Available: https://www.solidworks.com/. [Accessed: 07-Jul-2025].

25 | P a g e

## 15.0 DECLARATION OF ORIGINALITY

We hereby declare that this report is our own work and that

we have acknowledged all sources used.

Bremen, July 7, 2025, CHIMEZIE DANIEL CHIDI

Hamm, July 7, 2025, BERTRAND MUNGU CHO

Soest, July 7, 2025, GHIMIRE RIWAJ

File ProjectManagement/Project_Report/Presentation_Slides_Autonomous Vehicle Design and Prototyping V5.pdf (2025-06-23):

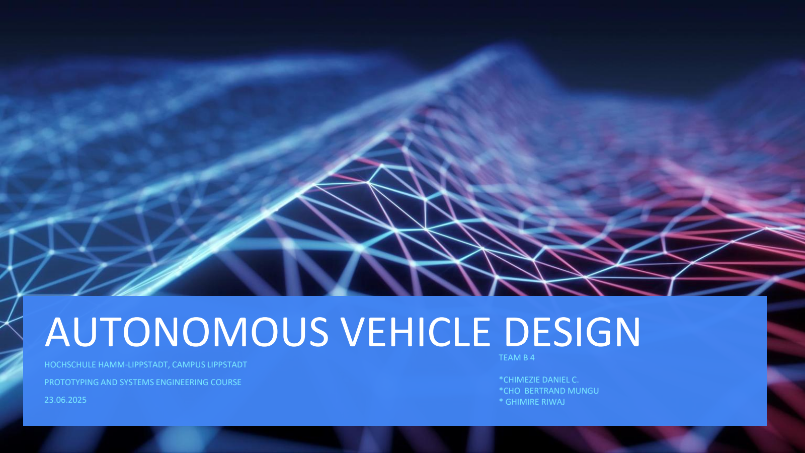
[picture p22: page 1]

# AUTONOMOUS VEHICLE DESIGN

HOCHSCHULE HAMM-LIPPSTADT, CAMPUS LIPPSTADT

PROTOTYPING AND SYSTEMS ENGINEERING COURSE

23.06.2025

TEAM B 4

*CHIMEZIE DANIEL C.
*CHO BERTRAND MUNGU
* GHIMIRE RIWAJ

# WHAT IS AN AUTONOMOUS VEHICLE ?

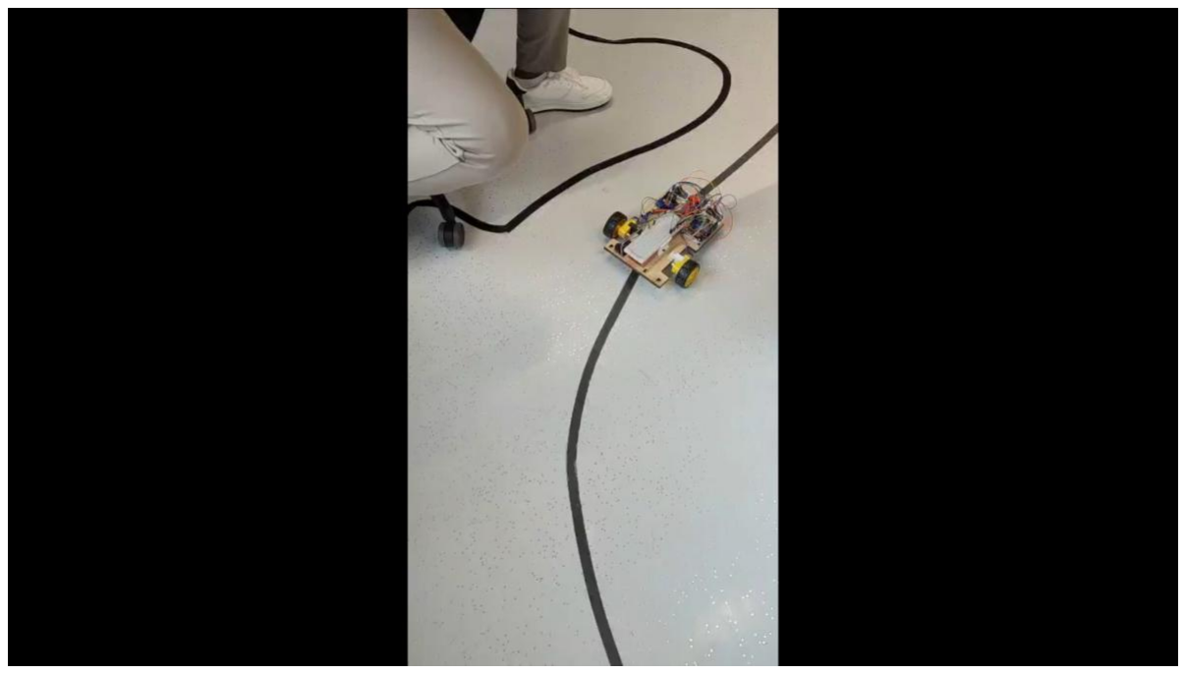
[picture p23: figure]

# AUTONOMOUS VEHICLE DESIGN

According to IEEE standards association: "An autonomous vehicle is a system capable of sensing its environment and operating without human involvement. Such systems are designed to navigate and perform driving functions without direct human input, using onboard sensors, processors, and actuators" [1].

Play the short video above by:
1. Place your mouse above the black image / select the video pan. Then, press alt+p on a German keyboard.
2. Alternatively, highlight the video pan above, you will see a nub | above to play the video manually.

# SYSTEM OVERVIEW

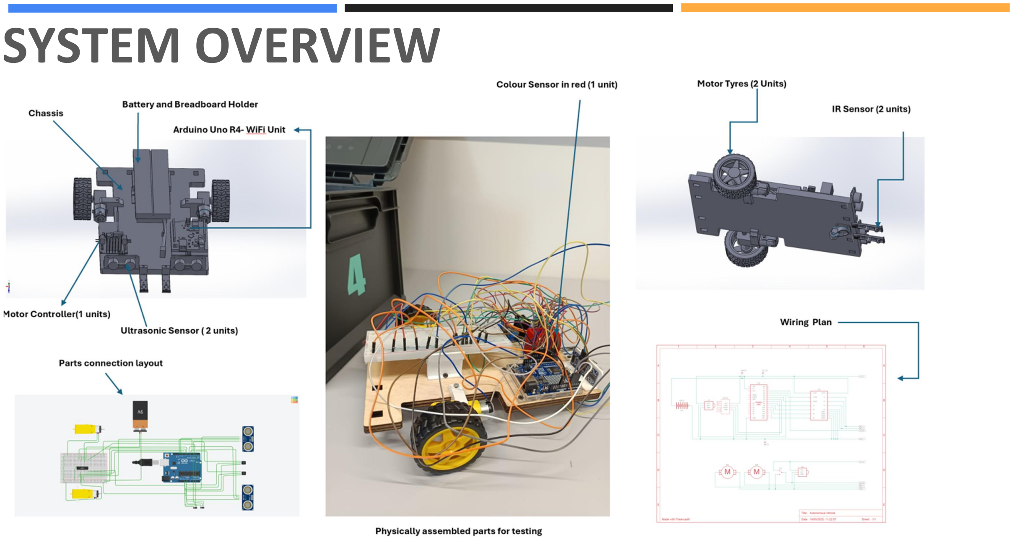
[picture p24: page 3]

# AUTONOMOUS VEHICLE DESIGN

# PROJECT OBJECTIVE

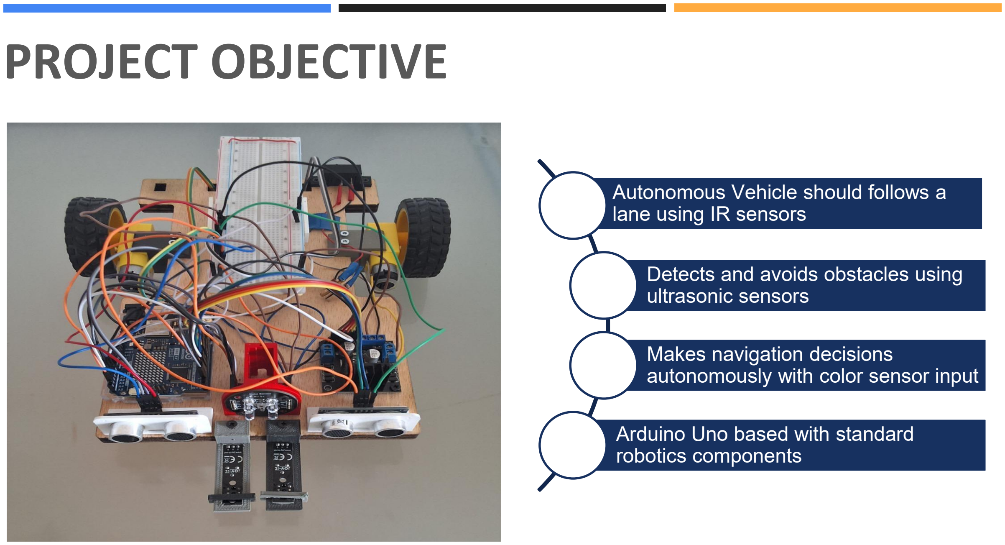
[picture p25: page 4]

# AUTONOMOUS VEHICLE DESIGN

Autonomous Vehicle should follows a lane using IR sensors

Detects and avoids obstacles using ultrasonic sensors

Makes navigation decisions autonomously with color sensor input

Arduino Uno based with standard robotics components

# SYSTEMS ENGINEERING DIAGRAMS


# AUTONOMOUS VEHICLE DESIGN

1. System Architecture (SysML BDD)

# SYSTEMS ENGINEERING DIAGRAMS


# AUTONOMOUS VEHICLE DESIGN

2. Requirement diagram

# SYSTEMS ENGINEERING DIAGRAMS


# AUTONOMOUS VEHICLE DESIGN

3. Internal Block Diagram

# SYSTEMS ENGINEERING DIAGRAMS


4. Use Case Diagram

# SYSTEMS ENGINEERING DIAGRAMS


# AUTONOMOUS VEHICLE DESIGN

5.0 Activity Diagram

# SYSTEMS ENGINEERING DIAGRAMS


# AUTONOMOUS VEHICLE DESIGN

6.0 State Machine Diagram

# SYSTEMS ENGINEERING DIAGRAMS


# AUTONOMOUS VEHICLE DESIGN

7.0 Parametric Diagram

# SYSTEMS ENGINEERING DIAGRAMS

AUTONOMOUS VEHICLE DESIGN; 8.0 Sequence Diagram

# CODING, TESTING AND IMPLEMENTATION

# AUTONOMOUS VEHICLE DESIGN


# AUTONOMOUS VEHICLE DESIGN

UPAAL ANALYSIS


# AUTONOMOUS VEHICLE DESIGN

Implementation Snapshot-Movement Logic


# AUTONOMOUS VEHICLE DESIGN

Implementation Snapshot- Act on Movement State


# AUTONOMOUS VEHICLE DESIGN

Implementation Snapshot- Setup code with setup function example


# AUTONOMOUS VEHICLE DESIGN

Implementation Snapshot- Inside Loop


# AUTONOMOUS VEHICLE DESIGN

Implementation Snapshot- Obstacle Checker and Detecting Color


# AUTONOMOUS VEHICLE DESIGN

Implementation Snapshot- PID Logic


# AUTONOMOUS VEHICLE DESIGN

Implementation Snapshot- Set Motor Speed

Implementation Snapshot- Color sensor


Challenges and solutions

1. IR Sensor Calibration; ❏Issue: Unreliable black tape detection; 4. Motor Control @ 12V; ❏Issue: Uncontrollable speed

❏Fix: Adjusted angle + threshold calibration

2.Ultrasonic Sensor Range; ❏Issue: Inconsistent obstacle readings ❏Fix: Tuned to 2-400 cm range + noise filtering; limits 5. Line Following PID; ❏Issue: Jerky turns ❏Fix: Implemented PID (Kp=10.0, Ki=0.00, Kd=10.0)

## 3.Color Sensor Stability

❏Issue: Fluctuating RGB values ❏Fix: Averaged readings + ratio normalization

❏Fix: Unmasked enable pins + PWM

Conclusion and Future Projections

➢Successfully built an autonomous vehicle using:
- Infrared sensors
- Ultrasonic sensors
- color sensor
➢System operated without human intervention using Arduino-based control. ➢Demonstrated stable navigation, responsive obstacle handling, and consistent performance on a contrast-based track.

Conclusion

➢Machine Learning Integration ➢Vision System Enhancement

Future Work

Reference

[1] IEEE Standards Association, Autonomous Systems Framework Working Group: P2040 Draft Standard for Framework for Autonomous Systems, IEEE, 2020. [Online]. Available: https://standards.ieee.org


# THANK YOU !

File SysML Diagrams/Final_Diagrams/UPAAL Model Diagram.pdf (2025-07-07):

MovingRight; Obstacle; MovingBackward; Park; MovingLeft; wait = 1; MovingForward; Start

© Group B Team 4 Systems Engineering and Prototyping course at HSHL Lippstadt Campus. SS 2025

UPAAL Model

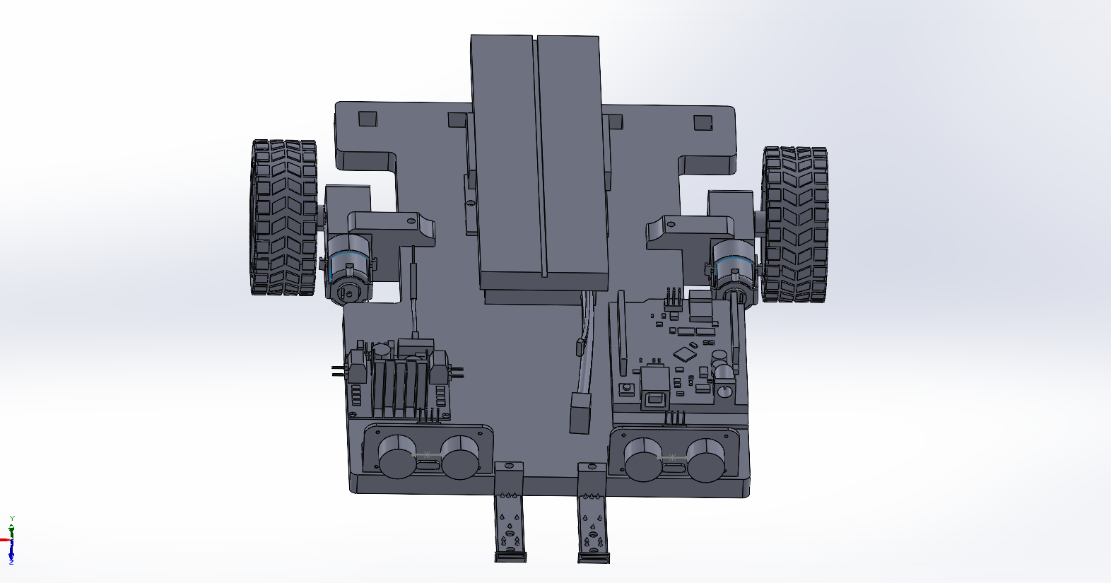
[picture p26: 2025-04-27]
3D CAD Model/Model_Design_In_Solidworks_Front view.png

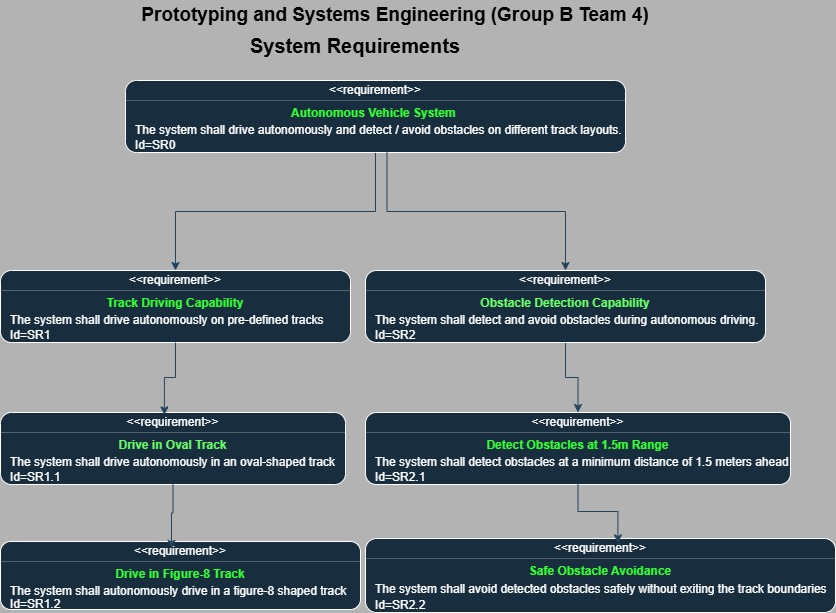
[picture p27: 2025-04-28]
SysML Diagrams/Final_Diagrams/Requirements_Diagram.jpg

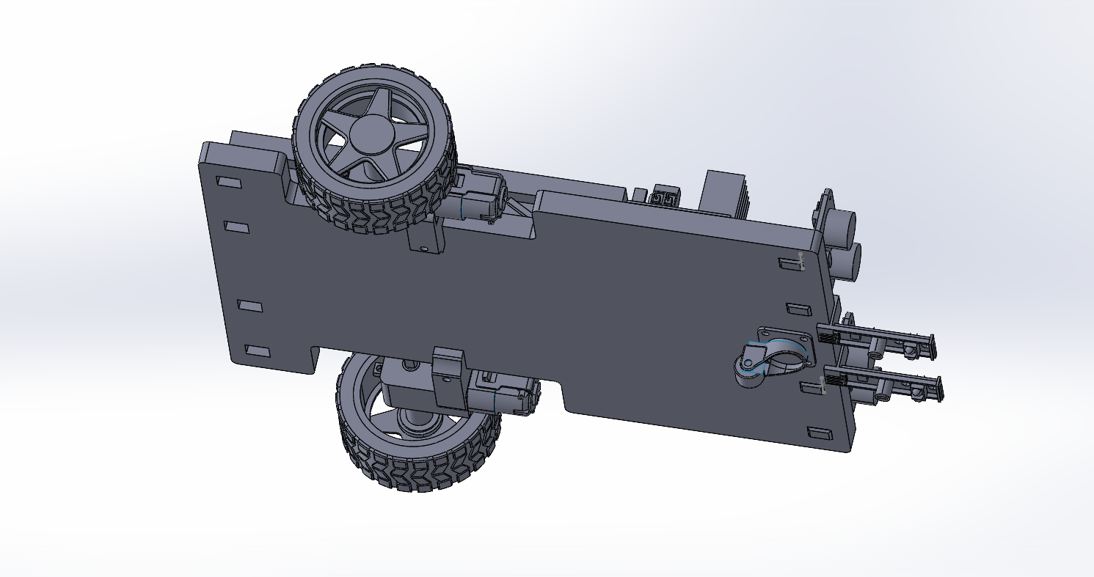
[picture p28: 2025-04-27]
3D CAD Model/Model_Design_In_Solidworks_Bottom view.png

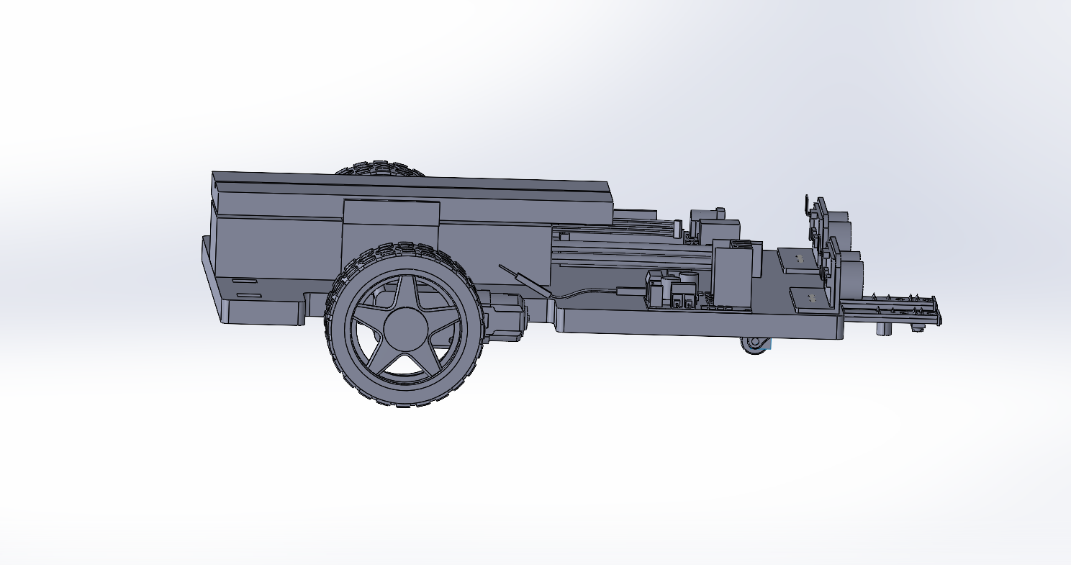
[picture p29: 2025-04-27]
3D CAD Model/Model_Design_In_Solidworks_Side view.png

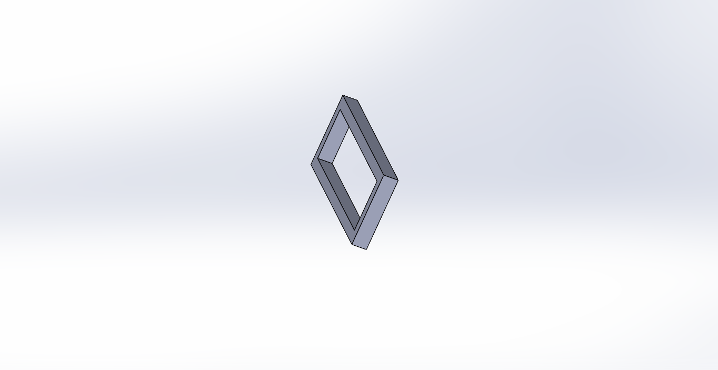
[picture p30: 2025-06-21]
3D CAD Model/IR Sensor Holder Clip.png

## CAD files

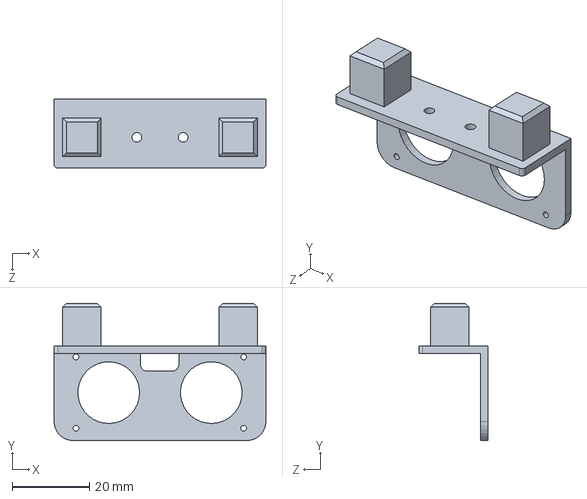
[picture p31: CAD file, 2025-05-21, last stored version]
3D CAD Model/ultrasonic holder1.SLDPRT
55.0 x 35.6 x 18.0 mm

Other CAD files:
3D CAD Model/ultrasonic holder1.STL

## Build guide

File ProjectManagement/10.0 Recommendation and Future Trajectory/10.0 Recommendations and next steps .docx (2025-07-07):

10. RECOMMENDATIONS AND NEXT STEPS

The autonomous vehicle project has successfully met its core objectives, including reliable lane following, obstacle avoidance, and colour-based decision making. To further enhance the system’s robustness, scalability, and practical applicability, the following recommendations and next steps are proposed:

1. Improve Sensor Fusion: Integrate data from multiple sensors (e.g., IR, ultrasonic, and camera modules) using sensor fusion techniques to enhance accuracy in complex environments.
2. Add Camera-Based Vision: Introduce a camera module with basic computer vision algorithms (e.g., OpenCV) to recognize traffic signs, lane markings, and dynamic obstacles beyond the capability of IR or color sensors.
3. Enhance Navigation Algorithms: Implement advanced algorithms such as A* or Dijkstra for path planning, and Kalman Filter for better localization and control under uncertain conditions.
4. Develop a Scalable Software Architecture: Refactor the current code into modular blocks to support future upgrades, debugging, and potential collaboration with other developers.
5. Test in Real-World Scenarios: Move beyond lab conditions and test the vehicle on larger, more dynamic tracks with real-world variations in lighting, surfaces, and obstacle types.
6. Add Remote Monitoring: Incorporate wireless communication (e.g., Bluetooth or Wi-Fi) for remote monitoring, telemetry, and control, allowing real-time feedback and data collection during operation.
7. Energy Optimization: Analyse battery usage and optimize motor control and sensor usage to extend operating time and improve energy efficiency.

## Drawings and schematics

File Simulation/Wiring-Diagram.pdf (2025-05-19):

A

1 | 2 | 3 | 4 | 5 | 6

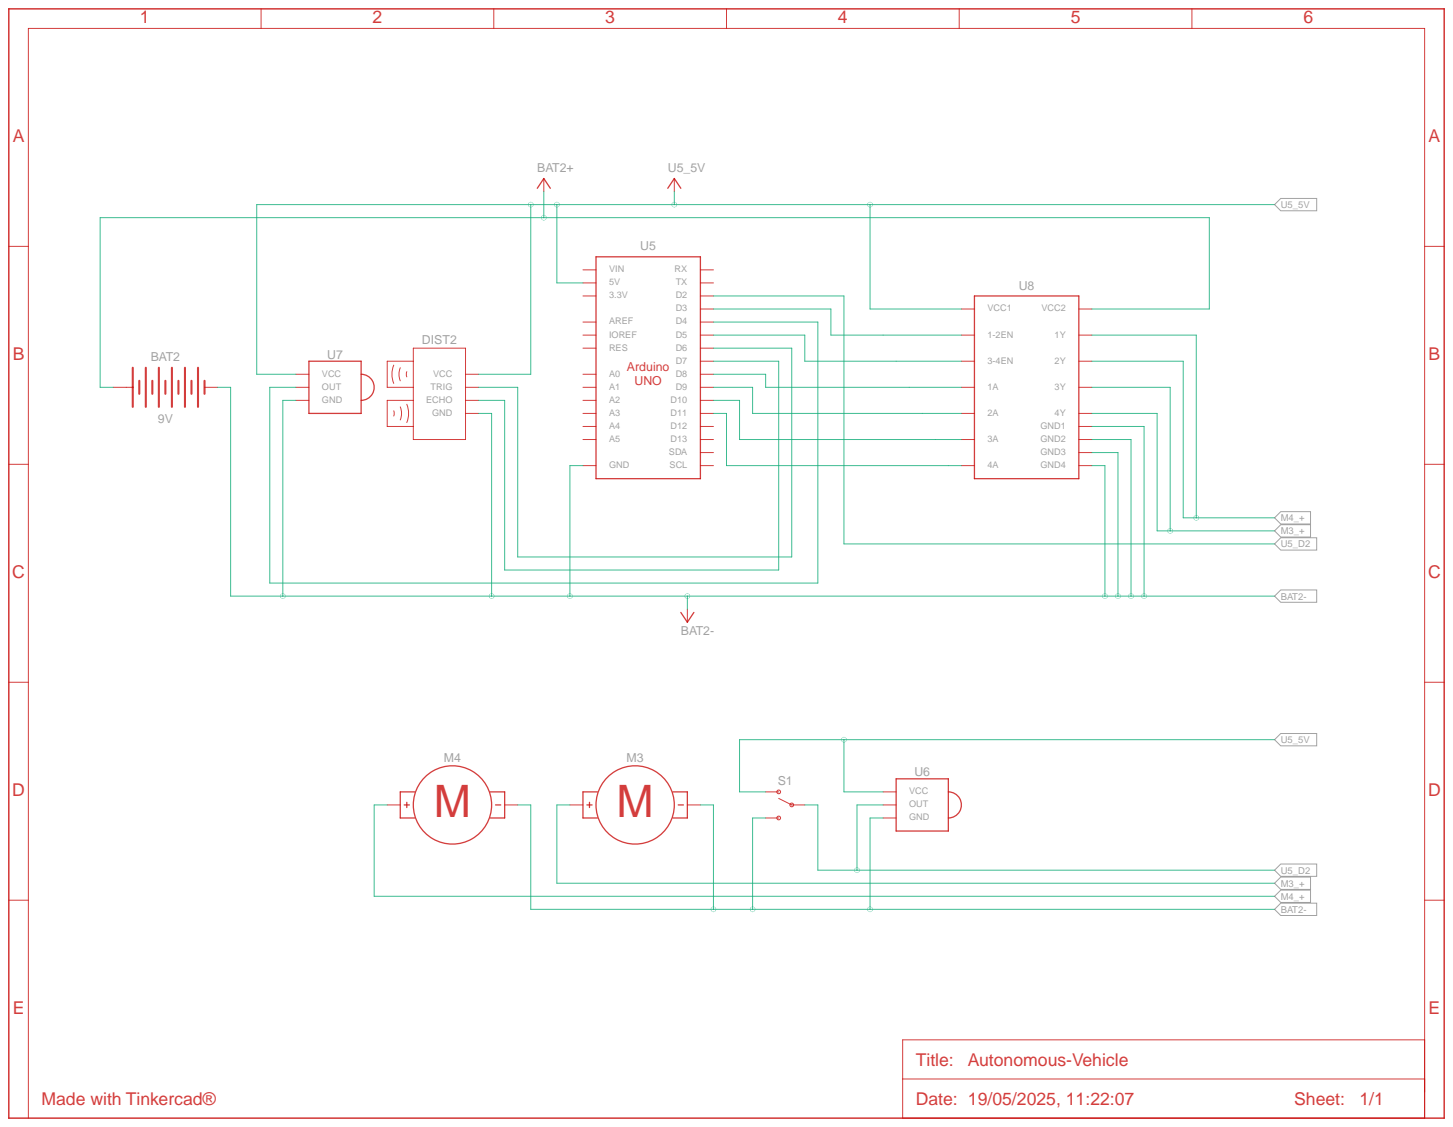
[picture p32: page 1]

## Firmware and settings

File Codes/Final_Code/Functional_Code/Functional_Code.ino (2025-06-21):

// === Motor control pins ===
const int enA = 3;  // PWM
const int in1 = 8;
const int in2 = 9;
const int enB = 5;  // PWM
const int in3 = 10;
const int in4 = 11;

// === IR sensors ===
const int irLeft = 2;
const int irRight = 4;

// === Ultrasonic front-left and front-right sensors ===
const int trigLeft = 6;
const int echoLeft = 7;
const int trigRight = 12;
const int echoRight = 13;

// === Color sensor pins ===
const int S0 = A0;
const int S1 = A1;
const int S2 = A2;
const int S3 = A3;
const int sensorOut = A4;

// === Motor speed settings ===
const float MOTOR_SPEED = 100;
const float TURN_SPEED = 60;

// === PID constants ===
float Kp = 10.0;
float Ki = 0.0;
float Kd = 10.0;
float previousError = 0;
float integral = 0;

// === Obstacle detection state ===
unsigned long lastObstacleCheck = 0;
const unsigned long obstacleCheckInterval = 200;
bool obstacleDetected = false;

// === Movement & line states ===
enum MovementState { STOP, FORWARD, SEARCH_LEFT, SEARCH_RIGHT };
MovementState currentState = STOP;

enum LastSeen { NONE, LEFT, RIGHT };
LastSeen lastSeenLine = NONE;

// === Color calibration ===
struct ColorCalibration {
  float ratioRG;
  float ratioRB;
};
ColorCalibration colorA = {0.595, 0.585};
ColorCalibration colorB = {0.561, 0.541};

bool colorDetectedForThisObstacle = false;
char lastDetectedColor = 'N';  // 'A', 'B', or 'N'

void setup() {
  // Motor
  pinMode(enA, OUTPUT);
  pinMode(in1, OUTPUT);
  pinMode(in2, OUTPUT);
  pinMode(enB, OUTPUT);
  pinMode(in3, OUTPUT);
  pinMode(in4, OUTPUT);

  // IR
  pinMode(irLeft, INPUT);
  pinMode(irRight, INPUT);

  // Ultrasonic
  pinMode(trigLeft, OUTPUT);
  pinMode(echoLeft, INPUT);
  pinMode(trigRight, OUTPUT);
  pinMode(echoRight, INPUT);

  // Color sensor
  pinMode(S0, OUTPUT);
  pinMode(S1, OUTPUT);
  pinMode(S2, OUTPUT);
  pinMode(S3, OUTPUT);
  pinMode(sensorOut, INPUT);
  digitalWrite(S0, HIGH);
  digitalWrite(S1, LOW);

  Serial.begin(9600);
  stopMotors();
}

void loop() {
  unsigned long currentMillis = millis();

  // Obstacle detection
  checkobstacle();


  // IR reading
  int leftIR = digitalRead(irLeft);
  int rightIR = digitalRead(irRight);

  // Track last seen
  if (leftIR == HIGH && rightIR == LOW) lastSeenLine = LEFT;
  else if (rightIR == HIGH && leftIR == LOW) lastSeenLine = RIGHT;

  // Determine movement state
  if (obstacleDetected && lastDetectedColor == 'A') {
    currentState = STOP;
  } else if (obstacleDetected && lastDetectedColor == 'B') {
    currentState = FORWARD;
  } else if (leftIR == LOW && rightIR == LOW) {
    if (lastSeenLine == LEFT) currentState = SEARCH_LEFT;
    else if (lastSeenLine == RIGHT) currentState = SEARCH_RIGHT;
    else currentState = STOP;
  } else {
    currentState = FORWARD;
  }

  // Act on movement state
  actOnState(currentState, leftIR, rightIR);
}

void actOnState(MovementState state, int leftIR, int rightIR) {
  switch (state) {
    case STOP:
      stopMotors();
      break;

    case FORWARD: {
      int error = leftIR - rightIR;
      float derivative = error - previousError;
      integral += error;
      float correction = Kp * error + Ki * integral + Kd * derivative;
      previousError = error;

      int leftSpeed = constrain(MOTOR_SPEED - correction, 0, 255);
      int rightSpeed = constrain(MOTOR_SPEED + correction, 0, 255);
      setMotorSpeed(leftSpeed, rightSpeed);
      break;
    }

    case SEARCH_LEFT:
      setMotorSpeed(-TURN_SPEED, TURN_SPEED);
      break;

    case SEARCH_RIGHT:
      setMotorSpeed(TURN_SPEED, -TURN_SPEED);
      break;
  }
}

void checkobstacle() {
  unsigned long currentMillis = millis();

  if (currentMillis - lastObstacleCheck >= obstacleCheckInterval) {
    int distanceLeft = getDistance(trigLeft, echoLeft);
    int distanceRight = getDistance(trigRight, echoRight);

    bool obstacleNow = ((distanceLeft > 0 && distanceLeft < 25) ||
                        (distanceRight > 0 && distanceRight < 25));

    if (obstacleNow && !colorDetectedForThisObstacle) {
      stopMotors();
      char detected = detectColor();
      lastDetectedColor = detected;
      colorDetectedForThisObstacle = true;

      if (detected == 'A') {
        Serial.println("Action: STOP for Color A");
        currentState = STOP;
        return;
      } else if (detected == 'B') {
        Serial.println("Action: AVOID OBSTACLE for Color B");
        avoidObstacle();
      }
    } else if (!obstacleNow) {
      colorDetectedForThisObstacle = false;
      lastDetectedColor = 'N';
    }

    obstacleDetected = obstacleNow;
    lastObstacleCheck = currentMillis;
  }
}

void avoidObstacle() {
  Serial.println("Avoiding obstacle: Reversing...");
  setMotorSpeed(-MOTOR_SPEED, -MOTOR_SPEED);

  // Reverse for 300ms while continuously checking obstacles but NOT checking line sensors
  unsigned long startTime = millis();
  while (millis() - startTime < 300) {
    checkobstacle();
    delay(10);
  }
  stopMotors();

  // Pivot left for 500ms with obstacle checking
  Serial.println("Pivoting left...");
  setMotorSpeed(-TURN_SPEED, TURN_SPEED);
  startTime = millis();
  while (millis() - startTime < 500) {
    checkobstacle();
    delay(10);
  }
  stopMotors();

  // Move forward half speed for 500ms with line search
  Serial.println("Moving forward to bypass obstacle...");
  setMotorSpeed(MOTOR_SPEED / 2, MOTOR_SPEED / 2);
  startTime = millis();
  while (millis() - startTime < 500) {
    checkobstacle();

    int leftIR = digitalRead(irLeft);
    int rightIR = digitalRead(irRight);
    if (leftIR == HIGH || rightIR == HIGH) {
      stopMotors();
      currentState = FORWARD;
      return;
    }
    delay(10);
  }
  stopMotors();

  // Another forward step with searchForLineDuringWindow
  if (searchForLineDuringWindow(500)) {
    return;
  }

  stopMotors();
  checkobstacle();

  // Pivot right to realign with path
  Serial.println("Realigning right...");
  setMotorSpeed(TURN_SPEED, -TURN_SPEED);
  startTime = millis();
  while (millis() - startTime < 700) {
    checkobstacle();

    int leftIR = digitalRead(irLeft);
    int rightIR = digitalRead(irRight);
    if (leftIR == HIGH || rightIR == HIGH) {
      stopMotors();
      currentState = FORWARD;
      return;
    }
    delay(10);
  }
  stopMotors();

  checkobstacle();

  // Move forward again to ensure clearance
  Serial.println("Moving forward again...");
  setMotorSpeed(MOTOR_SPEED, MOTOR_SPEED);
  startTime = millis();
  while (millis() - startTime < 500) {
    checkobstacle();

    int leftIR = digitalRead(irLeft);
    int rightIR = digitalRead(irRight);
    if (leftIR == HIGH || rightIR == HIGH) {
      stopMotors();
      currentState = FORWARD;
      return;
    }
    delay(10);
  }
  stopMotors();

  checkobstacle();

  // Final line search with searchForLineDuringWindow
  Serial.println("Searching for line...");
  if (searchForLineDuringWindow(1500)) {
    return;
  }

  stopMotors();
  Serial.println("Line not found, initiating search pattern...");

  for (int i = 0; i < 3; i++) {
    Serial.print("Sweep attempt "); Serial.println(i + 1);

    Serial.println(" → Nudge forward");
    setMotorSpeed(MOTOR_SPEED, MOTOR_SPEED);
    delay(400);
    stopMotors();

    int leftIR = digitalRead(irLeft);
    int rightIR = digitalRead(irRight);
    if (leftIR == HIGH || rightIR == HIGH) {
      Serial.println("Line found during left sweep!");
      stopMotors();
      currentState = FORWARD;
      return;
    }

    Serial.println(" → Sweep left");
    setMotorSpeed(-TURN_SPEED, TURN_SPEED);
    delay(500);
    stopMotors();

    leftIR = digitalRead(irLeft);
    rightIR = digitalRead(irRight);
    if (leftIR == HIGH || rightIR == HIGH) {
      Serial.println("Line found during left sweep!");
      stopMotors();
      currentState = FORWARD;
      return;
    }

    Serial.println(" → Sweep right");
    setMotorSpeed(TURN_SPEED, -TURN_SPEED);
    delay(1000);
    stopMotors();

    leftIR = digitalRead(irLeft);
    rightIR = digitalRead(irRight);
    if (leftIR == HIGH || rightIR == HIGH) {
      Serial.println("Line found during right sweep!");
      stopMotors();
      currentState = FORWARD;
      return;
    }

    Serial.println(" → Return to center");
    setMotorSpeed(-TURN_SPEED, TURN_SPEED);
    delay(500);
    stopMotors();
  }

  Serial.println("Line not found after search pattern. Stopping.");
  currentState = STOP;
}



// === Helper functions ===

void stopMotors() {
  analogWrite(enA, 0);
  analogWrite(enB, 0);
  digitalWrite(in1, LOW);
  digitalWrite(in2, LOW);
  digitalWrite(in3, LOW);
  digitalWrite(in4, LOW);
}

void setMotorSpeed(int leftSpeed, int rightSpeed) {
  if (leftSpeed > 0) {
    digitalWrite(in1, HIGH); digitalWrite(in2, LOW);
  } else if (leftSpeed < 0) {
    digitalWrite(in1, LOW); digitalWrite(in2, HIGH);
  } else {
    digitalWrite(in1, LOW); digitalWrite(in2, LOW);
  }

  if (rightSpeed > 0) {
    digitalWrite(in3, HIGH); digitalWrite(in4, LOW);
  } else if (rightSpeed < 0) {
    digitalWrite(in3, LOW); digitalWrite(in4, HIGH);
  } else {
    digitalWrite(in3, LOW); digitalWrite(in4, LOW);
  }

  analogWrite(enA, abs(leftSpeed));
  analogWrite(enB, abs(rightSpeed));
}

int getDistance(int trigPin, int echoPin) {
  digitalWrite(trigPin, LOW);
  delayMicroseconds(2);
  digitalWrite(trigPin, HIGH);
  delayMicroseconds(10);
  digitalWrite(trigPin, LOW);
  long duration = pulseIn(echoPin, HIGH, 10000);
  if (duration == 0) return -1;
  int cm = duration * 0.034 / 2;
  if (cm < 2 || cm > 400) return -1;
  return cm;
}

char detectColor() {
  const int samples = 5;
  long rSum = 0, gSum = 0, bSum = 0;

  for (int i = 0; i < samples; i++) {
    int r = readFrequency(LOW, LOW);
    int g = readFrequency(HIGH, HIGH);
    int b = readFrequency(LOW, HIGH);
    rSum += r; gSum += g; bSum += b;
    delay(100);
  }

  float rAvg = rSum / (float)samples;
  float gAvg = gSum / (float)samples;
  float bAvg = bSum / (float)samples;

  float ratioRG = rAvg / gAvg;
  float ratioRB = rAvg / bAvg;

  Serial.println("----------------------");
  Serial.print("R="); Serial.print(rAvg, 1);
  Serial.print(" G="); Serial.print(gAvg, 1);
  Serial.print(" B="); Serial.print(bAvg, 1);
  Serial.print(" | RatioRG="); Serial.print(ratioRG, 3);
  Serial.print(" RatioRB="); Serial.println(ratioRB, 3);

  float diffA = abs(ratioRG - colorA.ratioRG) + abs(ratioRB - colorA.ratioRB);
  float diffB = abs(ratioRG - colorB.ratioRG) + abs(ratioRB - colorB.ratioRB);

  if (diffA < diffB) {
    Serial.println("Detected Color: A");
    return 'A';
  } else {
    Serial.println("Detected Color: B");
    return 'B';
  }
}

int readFrequency(bool s2, bool s3) {
  digitalWrite(S2, s2);
  digitalWrite(S3, s3);
  delay(50);
  return pulseIn(sensorOut, LOW);
}

bool searchForLineDuringWindow(unsigned long maxDuration) {
  unsigned long startTime = millis();
  setMotorSpeed(MOTOR_SPEED / 1.8, MOTOR_SPEED / 1.8);

  while (millis() - startTime < maxDuration) {
    int leftIR = digitalRead(irLeft);
    int rightIR = digitalRead(irRight);

    if (leftIR == HIGH || rightIR == HIGH) {
      stopMotors();

      if (leftIR == HIGH && rightIR == LOW) lastSeenLine = LEFT;
      else if (rightIR == HIGH && leftIR == LOW) lastSeenLine = RIGHT;

      currentState = FORWARD;
      return true;
    }
  }

  stopMotors();
  return false;
}

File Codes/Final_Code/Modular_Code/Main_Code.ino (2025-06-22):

#include <Arduino.h>
#include "Motor.h"
#include "Motor_Controller.h"
#include "IR_Sensor.h"
#include "Ultrasonic_Sensor.h"
#include "Color_Sensor.h"
#include "PID_Controller.h"
#include "Movement_Controller.h"
#include "Obstacle_Handler.h"
#include "Movement_Types.h"
#include "Obstacle_Checker.h"

// === IR Sensor Setup ===
constexpr uint8_t irLeftPin = 2;
constexpr uint8_t irRightPin = 4;
IRSensor leftIRSensor(irLeftPin);
IRSensor rightIRSensor(irRightPin);

// === Ultrasonic Sensor Setup ===
constexpr uint8_t trigLeftPin = 6;
constexpr uint8_t echoLeftPin = 7;
constexpr uint8_t trigRightPin = 12;
constexpr uint8_t echoRightPin = 13;
UltrasonicSensor leftUltrasonic(trigLeftPin, echoLeftPin);
UltrasonicSensor rightUltrasonic(trigRightPin, echoRightPin);

// === Color Sensor Setup ===
constexpr uint8_t S0 = A0;
constexpr uint8_t S1 = A1;
constexpr uint8_t S2 = A2;
constexpr uint8_t S3 = A3;
constexpr uint8_t sensorOut = A4;
ColorSensor colorSensor(S0, S1, S2, S3, sensorOut);

// === Motor Setup ===
constexpr uint8_t enA = 3;
constexpr uint8_t in1 = 8;
constexpr uint8_t in2 = 9;
constexpr uint8_t enB = 5;
constexpr uint8_t in3 = 10;
constexpr uint8_t in4 = 11;
Motor leftMotor(enA, in1, in2);
Motor rightMotor(enB, in3, in4);
MotorController motorController(leftMotor, rightMotor);

// === PID Controller Setup ===
PIDController pid(10.0, 0.0, 10.0);

// === Movement & Obstacle Controllers ===
MovementController movementController(motorController, leftIRSensor, rightIRSensor, pid);
ObstacleChecker obstacleChecker(leftUltrasonic, rightUltrasonic, colorSensor);
ObstacleHandler obstacleHandler(motorController, movementController, obstacleChecker,
                                leftIRSensor, rightIRSensor);

// === Color Calibration Data ===
ColorCalibration colorA = {0.595, 0.585};
ColorCalibration colorB = {0.561, 0.541};

void setup() {
  Serial.begin(9600);

  // Initialize hardware components
  leftIRSensor.begin();
  rightIRSensor.begin();
  leftUltrasonic.begin();
  rightUltrasonic.begin();
  colorSensor.begin();
  leftMotor.begin();
  rightMotor.begin();

  motorController.stop();
  obstacleChecker.setColorCalibration(colorA, colorB);
}

void loop() {
  // Check for obstacles
  obstacleChecker.check();

  if (obstacleChecker.isObstacleDetected()) {
    motorController.stop();
    delay(100);
    obstacleChecker.check(false);  // Check color while stopped

    char color = obstacleChecker.getLastDetectedColor();
    if (color == 'A') {
      Serial.println("Action: STOP for Color A");
    } else if (color == 'B') {
      Serial.println("Action: AVOID OBSTACLE for Color B");
      obstacleHandler.handleObstacle();
    }
  }

  // Update movement state (IR + obstacle + color)
  movementController.updateState(
    obstacleChecker.isObstacleDetected(),
    obstacleChecker.getLastDetectedColor(),
    movementController.getCurrentStateRef(),
    movementController.getLastSeenRef()
  );

  // Act based on the current movement state
  movementController.act(movementController.getCurrentState());
}

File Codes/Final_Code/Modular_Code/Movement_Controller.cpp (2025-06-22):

#include "Movement_Controller.h"

MovementController::MovementController(MotorController& motorCtrl, IRSensor& leftIR, IRSensor& rightIR, PIDController& pidCtrl)
  : motorController(motorCtrl), leftIRSensor(leftIR), rightIRSensor(rightIR), pid(pidCtrl) {}


void MovementController::updateState(bool obstacleDetected, char lastDetectedColor, MovementState& currentStateRef, LastSeen& lastSeenRef) {
  bool leftIR = leftIRSensor.isLineDetected();
  bool rightIR = rightIRSensor.isLineDetected();

  if (leftIR && !rightIR) lastSeenRef = LEFT;
  else if (rightIR && !leftIR) lastSeenRef = RIGHT;

  if (obstacleDetected && lastDetectedColor == 'A') {
    currentStateRef = STOP;
  } else if (obstacleDetected && lastDetectedColor == 'B') {
    currentStateRef = FORWARD;
  } else if (!leftIR && !rightIR) {
    if (lastSeenRef == LEFT) currentStateRef = SEARCH_LEFT;
    else if (lastSeenRef == RIGHT) currentStateRef = SEARCH_RIGHT;
    else currentStateRef = STOP;
  } else {
    currentStateRef = FORWARD;
  }
}

void MovementController::act(MovementState state) {
  switch (state) {
    case STOP:
      motorController.stop();
      break;

    case FORWARD: {
      int error = leftIRSensor.isLineDetected() - rightIRSensor.isLineDetected();
      float correction = pid.compute(error);

      int leftSpeed = constrain(baseSpeed - correction, 0, 255);
      int rightSpeed = constrain(baseSpeed + correction, 0, 255);
      motorController.setSpeed(leftSpeed, rightSpeed);
      break;
    }

    case SEARCH_LEFT:
      motorController.setSpeed(-searchSpeed, searchSpeed);
      break;

    case SEARCH_RIGHT:
      motorController.setSpeed(searchSpeed, -searchSpeed);
      break;
  }
}

// === Missing implementations that must be added ===

MovementState& MovementController::getCurrentStateRef() {
  return currentState;
}

LastSeen& MovementController::getLastSeenRef() {
  return lastSeenLine;
}

MovementState MovementController::getCurrentState() const {
  return currentState;
}

void MovementController::setCurrentState(MovementState state) {
  currentState = state;
}

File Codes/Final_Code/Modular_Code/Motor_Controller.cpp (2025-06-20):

#include "Motor_Controller.h"

MotorController::MotorController(Motor& leftMotor, Motor& rightMotor)
  : _leftMotor(leftMotor), _rightMotor(rightMotor) {}

void MotorController::setSpeed(int leftSpeed, int rightSpeed) {
  // Determine direction and speed for left motor
  Motor::Direction leftDirection = (leftSpeed >= 0)
    ? Motor::Direction::FORWARD
    : Motor::Direction::BACKWARD;

  Motor::Direction rightDirection = (rightSpeed >= 0)
    ? Motor::Direction::FORWARD
    : Motor::Direction::BACKWARD;

  _leftMotor.setSpeed(abs(leftSpeed), leftDirection);
  _rightMotor.setSpeed(abs(rightSpeed), rightDirection);
}

void MotorController::stop() {
  _leftMotor.stop();
  _rightMotor.stop();
}

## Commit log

2025-04-26 Create First SysML Diagrams
    Focused on requirements, including Requirements Diagrams, Use Case
    Diagrams,
2025-04-27 USE CASE DIAGRAM ADVANCED
2025-04-27 Create Scheduling
    This would be used to share and track our progress on team work level.
    What has to be done ( issues pending)
    Who are assigned to complete it.
    When should it be delivered
    Status Review of results as a team
2025-04-27 Add files via upload
    This is project planning sheet to track our progress as agreed in our meeting on Zoom yesterday.
    We would update details in it on regular basis and track our progress.
    [Project Planner for Prototyping and Systems Engineering_(Group B Team 4).xlsx]
2025-05-02 Create 3D CAD Model
2025-05-02 Rename Task 2/Model_Design_In_Solidworks_Bottom view.png to 3D CAD Models
2025-05-02 Update and rename TinkerCad_Simulationrd.brd to TinkerCad_Simulationrd.brd
    [TinkerCad_Simulationrd.brd]
2025-05-05 Create Arduino Code
2025-05-17 Update Arduino Code
2025-05-21 Added P controller and error mechanism in IR sensor detection of line and have switch case
2025-05-21 Ultrasonic_Sensor Holder
    [ultrasonic holder1.SLDPRT]
2025-05-24 Create Arduino Uno R4 WiFi
2025-05-24 Add files via upload
    This is our Arduino Uno R4 WiFi Data sheets
2025-05-24 Add files via upload
    This is our color sensor manual and data sheets
2025-05-24 Add files via upload
    This is RGB test-sheet for calibration of colour sensor.
2025-05-24 Add files via upload
    This is our ultrasonic sensor manual and data sheets in English
2025-05-24 Add files via upload
    This is data sheet only for Ultrasonic Sensor.
2025-05-24 Add files via upload
    This is the motor driver board
2025-05-25 Motor wiring changes
2025-05-26 Update Code review phase 1_HighSpeedMotorError_Correction
    Code for motor only
2025-05-26 Create Motor
2025-05-26 Create Ultrasonic Sensor
2025-05-26 Create IR Sensor
2025-05-26 Create Motor_Testing
2025-06-02 Create UltraSonic_Raw_File
2025-06-05 Add files via upload
    This is the video of when we had our first success with IR sensor tracking the lines and sensing obstacles.
2025-06-07 Proper code V2
    This is the stage of code we are in right now
2025-06-07 Create Ultrasonic_Sensor_Readings
2025-06-07 Add files via upload
    Video with IR Sensor working well across the track
2025-06-16 Create MotorTesting_Raw_File
2025-06-16 Update MotorTesting_Raw_File
2025-06-28 Milestones and their status ( on track, delays, deadlines)
2025-07-04 Update and rename Milestones and their status ( on track, delays, deadlines) to Progress_Summary_Latex_Format
2025-07-06 Delete ProjectManagement/Project Planner for Prototyping and Systems Engineering_(Group B Team 4) .xlsx
    This I created earlier. I am removing it here since the new update will go into timelines and schedules
    [Project Planner for Prototyping and Systems Engineering_(Group B Team 4) .xlsx]
2025-07-07 Create Initialization of Sensors and Actuators
2025-07-07 Update Initialization of Sensors and Actuators
2025-07-07 Update and rename Initialization of Sensors and Actuators to Initialization of Sensors and Actuators_Latex
